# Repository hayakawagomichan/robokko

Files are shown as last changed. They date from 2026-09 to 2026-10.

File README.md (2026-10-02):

# なかよし！ロボっこキット — ATOM S3R

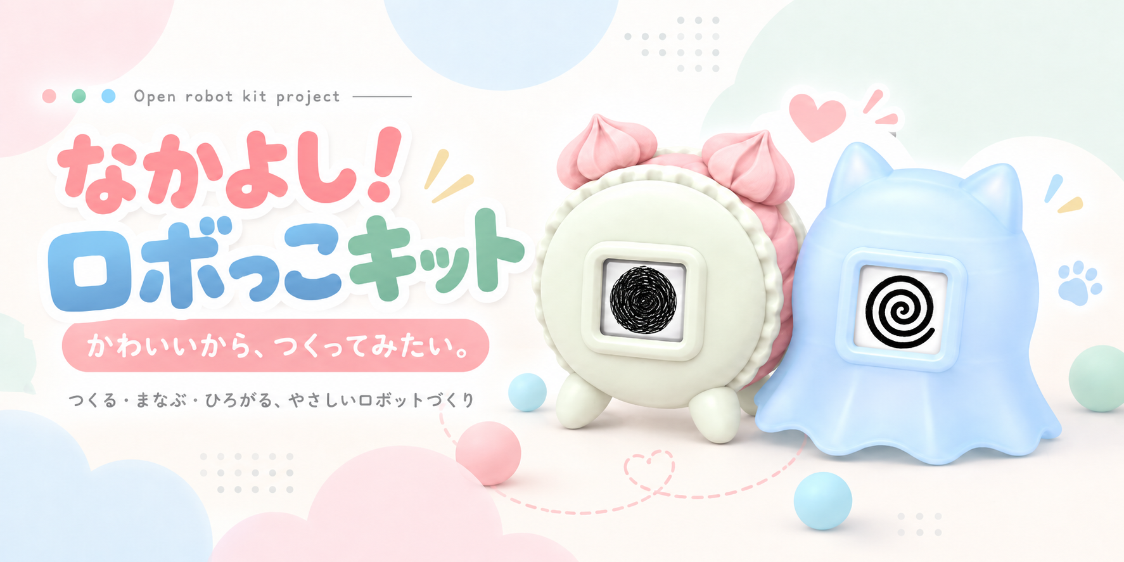
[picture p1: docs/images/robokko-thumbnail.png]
なかよし！ロボっこキット。かわいいから、つくってみたい。


**かわいいから、つくってみたい。気づいたら、ちゃんとロボットをつくってた。**

画面に顔を出して、サーボモーターで動く手のひらサイズのロボットです。
プログラム・作り方・3D印刷データを公開しています。

## 最初にお読みください

- **3Dプリント部品は高温で変形します。** 高温になる場所に置かないでください。
- **ATOMのディスプレイは、強く押し込むと割れることがあります。** 操作は軽く押してください。
- **サーボに負荷がかかるとATOMが再起動することがあります。** 誤った取り付けや、負荷がかかったまま動かし続けるとサーボが壊れる可能性があります。引っかかったら電源を切って確認してください。

**マカロンちゃんはバッテリー必須（組み立て後のUSB給電は非対応）。おばけねこはUSB・対応バッテリーの両方で使えます。**

## 作り方・必要なもの

| 開くページ | 内容 |
| --- | --- |
| [買い物リスト](docs/shopping-list.md) | 電子部品・道具の通販リンクと店舗案内 |
| [3D印刷データ](docs/printing.md) | キャラクター別の部品・個数・Bambu用設定 |
| [写真つき説明書（PDF）](docs/assembly.md) | マカロンちゃん・おばけねこの組み立て |
| 解説動画：[マカロンちゃん](https://youtu.be/42XKh_sF3WY) ／ [おばけねこ](https://youtu.be/PJhalL-63JU) | 組み立ての流れを動画で見る |

## はじめに

以下は **VS Code＋PlatformIO IDE拡張** で、ATOM S3Rにプログラムを書き込む手順です。
用意するものは **PC・ATOM S3R・データ通信できるUSBケーブル**（本体側はType-C）。書き込み済みの方は[配線](#servo-wiring)から進めます。
マカロンも、組み立て前の書き込み・動作確認ではATOM単体をUSBで接続します。

## 1. アプリを準備する（初回だけ）

1. [VS Code](https://code.visualstudio.com/)をインストールします。
2. 左端の「拡張機能」で **PlatformIO IDE** を検索し、提供元がPlatformIOのものをインストールします。
3. 準備が終わるまで待ちます。再起動を求められたらVS Codeを再起動します。

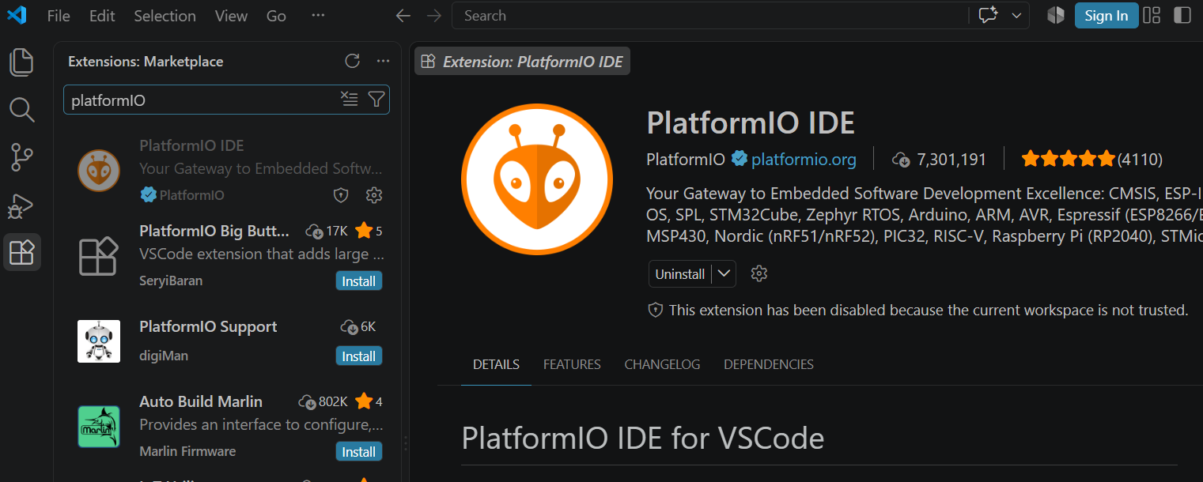
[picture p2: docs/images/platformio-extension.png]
PlatformIO IDE拡張の画面


画像は導入済みの例です。初めて入れるときは「Install」を押します。

## 2. ダウンロードしてフォルダを開く

1. [GitHubのトップ](https://github.com/hayakawagomichan/robokko)で **Code → Download ZIP** を押します。
2. ZIPを展開します。Windowsは右クリック →「すべて展開」、Macはダブルクリック。
3. フォルダを **英数字だけの場所** に置きます。Windowsの例：`C:\robokko`、Macの例：`/Users/hanako/robokko`。途中に日本語があるとビルドに失敗する場合があります。
4. VS Codeで **ファイル → フォルダーを開く** を選び、`platformio.ini` が直接入っているフォルダを開きます。

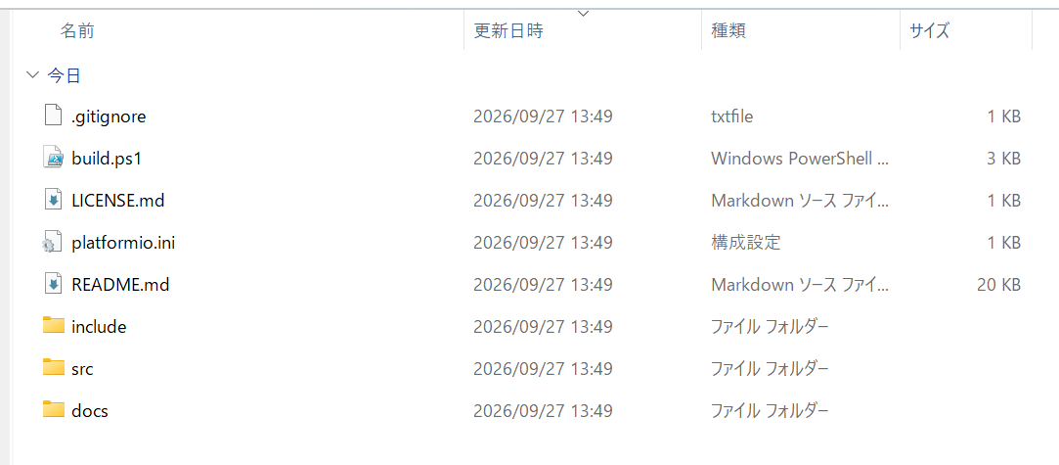
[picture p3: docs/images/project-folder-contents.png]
platformio.iniが入ったフォルダを開きます


`src` はプログラム本体、`include` は顔画像などのデータです。**書き込むだけなら編集不要**です。
フォルダを信頼するか聞かれたら、このGitHubから入手したものと確認して信頼します。初回は道具のダウンロードが終わるまで待ってください。

## 3. 本体をつなぎ、Uploadする

1. **サーボとバッテリーを外し、ATOM S3RだけをUSBでPCにつなぎます。**
2. VS Code左下の **右矢印「→ Upload」** を押します。
3. USBを抜かずに待ち、ターミナルに **SUCCESS** が出たら書き込み完了です。

VS Code左下の右矢印がUploadです。赤枠のボタンを押します。

画像はボタン位置の例です。初回の準備が終わってから押してください。Uploadにはビルドも含まれるので、Buildを別に押す必要はありません。
書き込むと本体の元のプログラムは置き換わります。

## 4. 顔を確認する

USBをつないだまま待つと顔が出ます。本体を横にすると寝顔、縦に戻すと通常の顔になります。
確認できたら **USBを抜いて**、次の配線へ進みます。

## 5. サーボをつなぐ

**配線は電源OFFで行います。** Groveケーブルと4ピン変換コネクタを使い、線の役割を合わせて接続します。

| 役割 | Grove側 | SG90側（今回の実物） |
| --- | --- | --- |
| GND | 黒 | 茶 |
| 5V | 赤 | オレンジ |
| 信号 | 黄・G2 | 黄 |
| 使わない | 白・G1 | 接続しない |

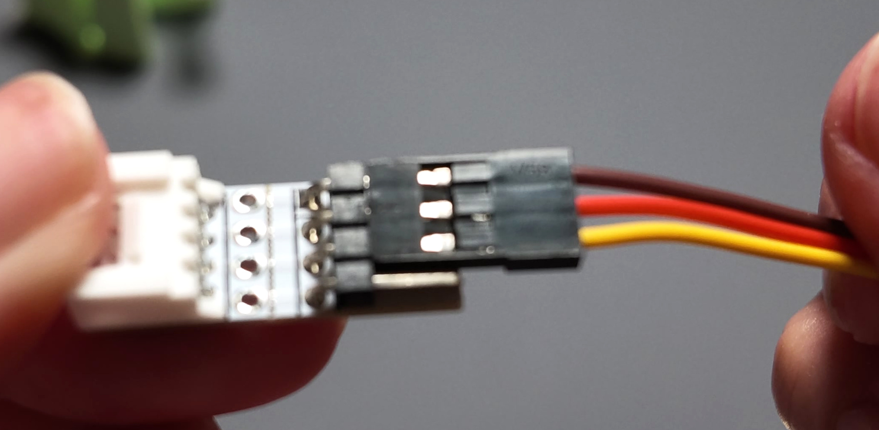
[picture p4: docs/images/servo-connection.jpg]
実物の配線写真


**SG90は製品によって線色が異なります。** 色だけで判断せず、購入品の仕様・端子表示を確認してください。
最初はサーボを機構へ取り付けず、回る部分に物が当たらない状態でUSBをつなぎます。電源を入れるとサーボが動きます。

## 6. 動かしてみる

| 操作 | 動作 |
| --- | --- |
| 画面を1回押す | 往復する／もう1回で元の位置へ戻って止まる |
| 本体を横向きに約2秒保つ | 寝顔になって休止。縦に戻すと往復を再開 |
| 素早く2回押す（ダブルクリック） | **サーボホーンを取り付ける位置へ動き、↑を表示** |
| 本体を軽く振る | 渦巻き顔になる |

ホーンを取り付ける前に、往復を1回押しで止め、**完全に停止してから**ダブルクリックしてください。
[組み立て説明書](docs/assembly.md)へ進みます。次からは電源を入れるだけで遊べます。

## うまくいかないとき

[Uploadボタンがない・書き込めない・サーボが動かない場合はこちら](docs/troubleshooting.md)。

<details>
<summary>プログラムを編集する方へ</summary>

| ファイル | 中身 |
| --- | --- |
| `src/main.cpp` | 顔・ボタン・センサー・サーボの動作 |
| `include/img_*.h` | 顔画像データ |
| `platformio.ini` | ボード設定・使用ライブラリ |
| `build.ps1` | Windows用の書き込み補助 |

PlatformIO espressif32 6.7.0 / Arduino-ESP32 2.0.16。UIFlow2用ではありません。
CLIからの書き込みは `pio run -t upload`。
使用ライブラリ：[M5Unified](https://github.com/m5stack/M5Unified) 0.2.23、[M5GFX](https://github.com/m5stack/M5GFX) 0.2.30、[ESP32Servo](https://github.com/madhephaestus/ESP32Servo) 1.2.1。

</details>

## 利用条件・お問い合わせ

個人利用・非商用ワークショップで利用できます。改造データの再配布は非営利に限り、**Forkまたはクレジット表記＋リンク**で利用できます。元リポジトリへの表示が残るForkでは、追加のクレジット表記は不要です。営利販売は禁止、自分で使う部品の印刷代行はOKです。[利用条件の詳細](LICENSE.md)

**ワークショップ・商用利用の相談 → [なかよしロボティクス](https://nakayoshi.tech)**
不具合の報告 → [GitHub Issues](https://github.com/hayakawagomichan/robokko/issues)

企画・制作：なかよしロボティクス ／ 企画・デザイン：ハヤカワ五味 ／ 設計・3Dデータ：uni

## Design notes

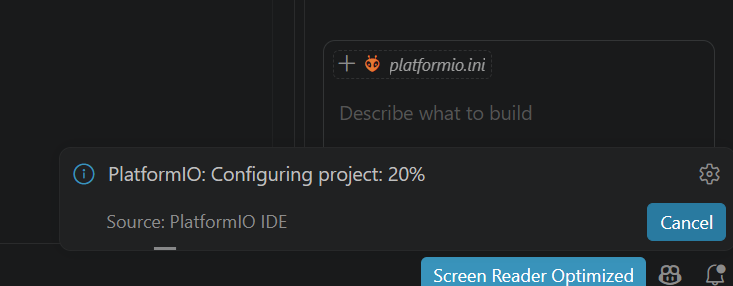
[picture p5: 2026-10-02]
docs/images/platformio-configuring-project.png

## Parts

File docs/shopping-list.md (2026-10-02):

# ロボっこの買い物リスト

[← 書き込み・配線手順](../README.md)

## 1台分の電子部品

価格は2026年9月26日確認・税込・送料別です。現在の価格・在庫は各商品ページをご確認ください。

| 買うもの | 1台に使う数 | 通販の商品リンク・目印 | 購入単位と参考価格 |
| --- | --- | --- | --- |
| 画面付きマイコン本体 | 1台 | スイッチサイエンス：[ATOMS3R（8MB PSRAM搭載）](https://www.switch-science.com/products/9915) / 商品番号 **9915**・型番 **M5STACK-C126** | 1台 **3,531円** |
| サーボモーター | 1個 | 秋月電子通商：[マイクロサーボ9g SG90](https://akizukidenshi.com/catalog/g/g108761/) / 販売コード **108761** | 1個 **650円** |
| 本体と変換コネクタをつなぐケーブル | 1本 | スイッチサイエンス：[M5Stack用GROVE互換ケーブル 10 cm](https://www.switch-science.com/products/5213) / 商品番号 **5213**・型番 **M5STACK-A034**（旧表記：M5STACK-CABLE-10） | **5本セット**で **528円** |
| サーボをつなぐ変換コネクタ | 1個 | スイッチサイエンス：[GROVE用4ピン変換コネクタ](https://www.switch-science.com/products/7093) / 商品番号 **7093**・型番 **M5STACK-A099** | **10個セット**で **847円** |
| PCと本体をつなぐUSBケーブル | 1本 | 手持ちの**データ通信対応**ケーブルでOK。PCにUSB-A端子がある場合の購入例：秋月電子通商 [USB2.0 Type-A ⇔ Type-C 1.5 m](https://akizukidenshi.com/catalog/g/g113563/) / 販売コード **113563** | 購入例は1本 **130円** |

- 本体は**画面付きATOM S3R（C126）**、サーボは通常のSG90を選びます。Liteや360°連続回転サーボは対象外です。
- USBケーブルは**データ通信対応**で、PC側の端子に合うものを選んでください。
- SG90は製品によって線色が異なります。[配線表](../README.md#servo-wiring)と購入品の仕様を照合してください。

## 費用の目安

本体・サーボ・Groveケーブル・変換コネクタを販売単位で購入すると **5,556円＋送料**。USBケーブルも上の例で買うと **5,686円＋送料**です。
セットを分けた場合、1台に使う基本の電子部品は約4,371円分。**マカロンには下記バッテリー代も必須**です。3D印刷・道具の代金は別です。

## バッテリー（マカロンは必須／おばけねこは任意）

**マカロンちゃんはバッテリー必須です。組み立て後のUSB給電には対応していません。**
マカロンちゃんと、コードレスで使うおばけねこには、[ATOMIC バッテリーベース](https://www.switch-science.com/products/10375)を1個用意します。
型番 **M5STACK-A151／200 mAh**。1個 **1,232円**（2026年10月2日確認・税込・送料別）。

- 使うとき：スイッチ **ON**。
- 充電するとき：スイッチ **OFF**でATOMにUSBを接続。青LEDが充電中、緑LEDが完了です。
- 着脱するとき：USBを抜き、スイッチをOFFにします。

出力上限は5 V・300 mA。使い方は[メーカー説明](https://docs.m5stack.com/en/atom/Atomic_Battery_Base)へ。
バッテリーを使わないおばけねこには、[バッテリーなし用スペーサー](printing.md#common)が1個必要です。マカロンにはスペーサーを使いません。

## 組み立てに使うもの

| 用意するもの | 購入・入手先 |
| --- | --- |
| 外装・機構の部品 | [3D印刷データ・必要個数](printing.md) |
| 精密プラスドライバー | サーボ付属のねじに合うもの |
| 接着剤 | 瞬間接着剤、または[ボンド ウルトラ多用途SU](https://www.amazon.co.jp/dp/B0CJWWBTYD)など |

接着は[説明書](assembly.md)の位置に行い、動く部分には付けないでください。乾燥時間は接着剤の説明に従います。

## 店頭で買うなら（東京・秋葉原）

| 店 | 買うもの | 所在地・営業時間 |
| --- | --- | --- |
| [千石電商 秋葉原本店](https://www.sengoku.co.jp/shop_01.html) | [ATOM S3R](https://www.sengoku.co.jp/mod/sgk_cart/detail.php?code=EEHD-6J74)・接続部品 | 外神田1-8-6 丸和ビル／11:00〜19:00 |
| [秋月電子通商 秋葉原店](https://akizukidenshi.com/catalog/pages/akiba.aspx) | SG90・USBケーブル | 外神田1-8-3 野水ビル／11:00〜18:00 |

店舗情報は2026年9月26日確認。休業日・店頭在庫は各店の公式案内をご確認ください。

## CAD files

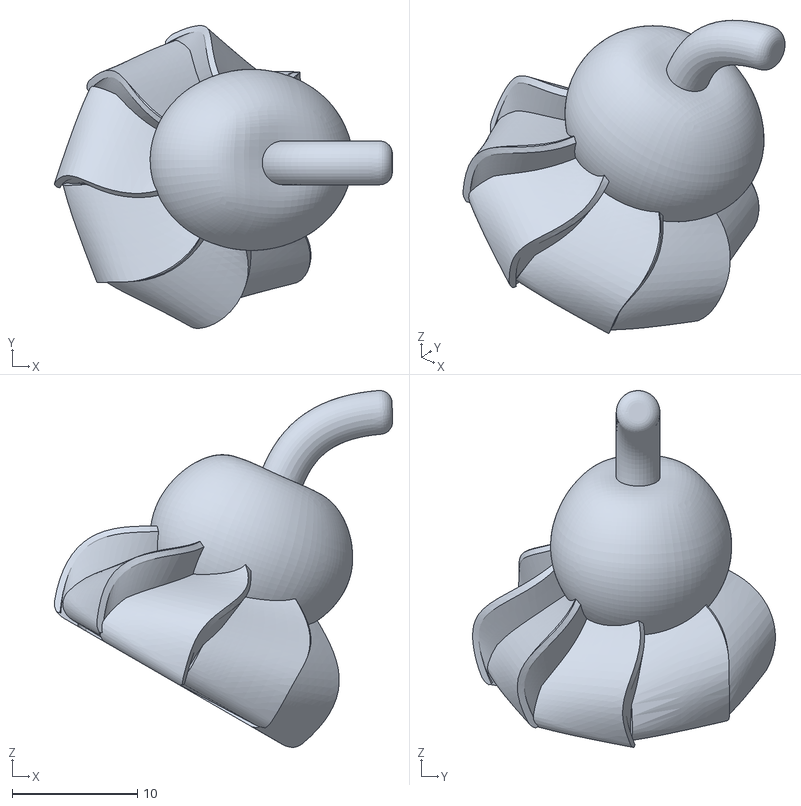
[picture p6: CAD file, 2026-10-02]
models/別仕様_要確認/マカロン/さくらんぼホイップ.stl
27.0 x 24.2 x 28.5

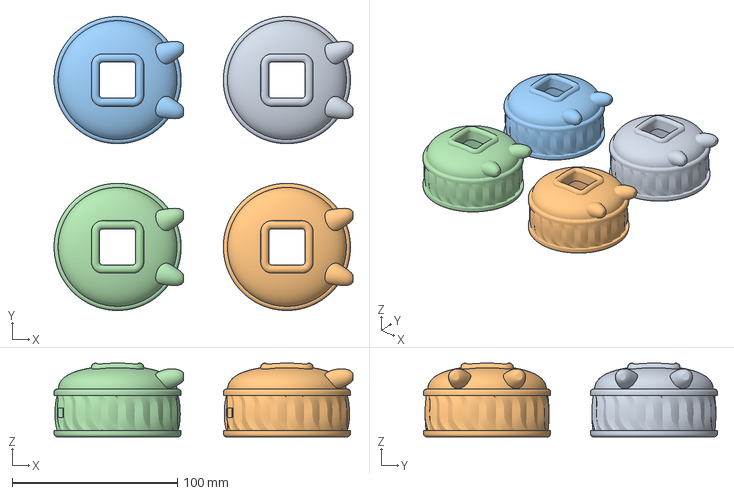
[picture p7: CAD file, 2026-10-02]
models/印刷設定_BambuP2S専用/マカロン_本体_4台分.3mf
181.0 x 178.0 x 44.7 mm
マカロン前クリアランス0.3.stl x 4

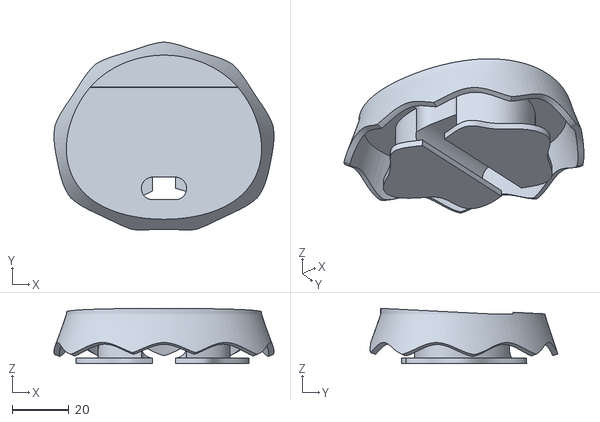
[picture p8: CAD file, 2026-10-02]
models/印刷部品/おばけねこ/足.stl
77.8 x 66.4 x 19.5

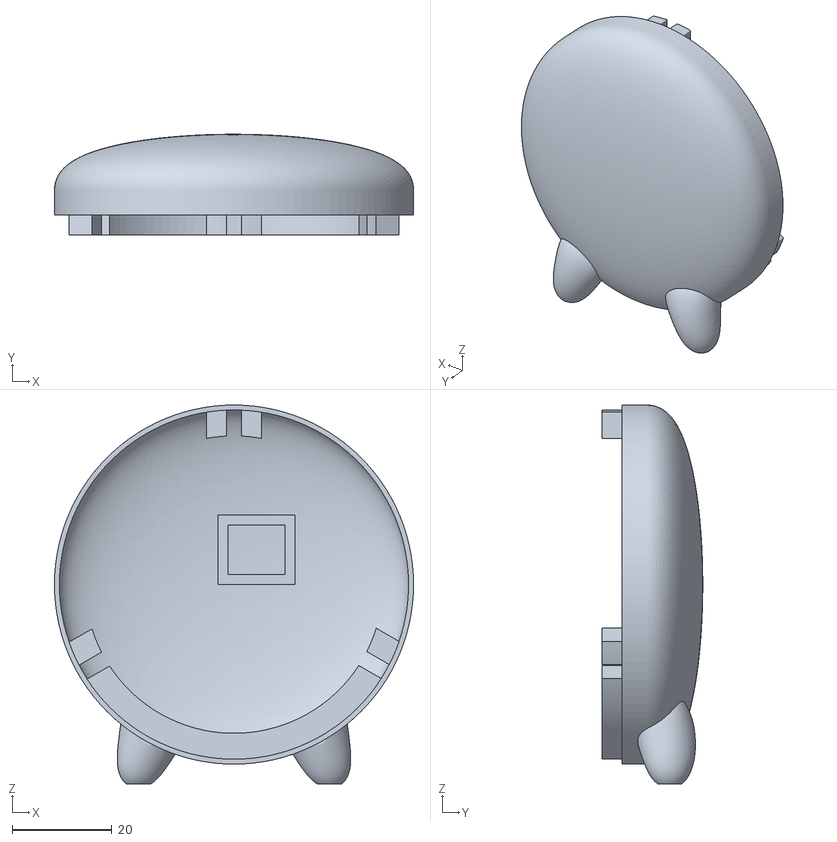
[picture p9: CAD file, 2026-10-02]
models/印刷部品/マカロン/ふた.stl
72.0 x 20.2 x 76.0

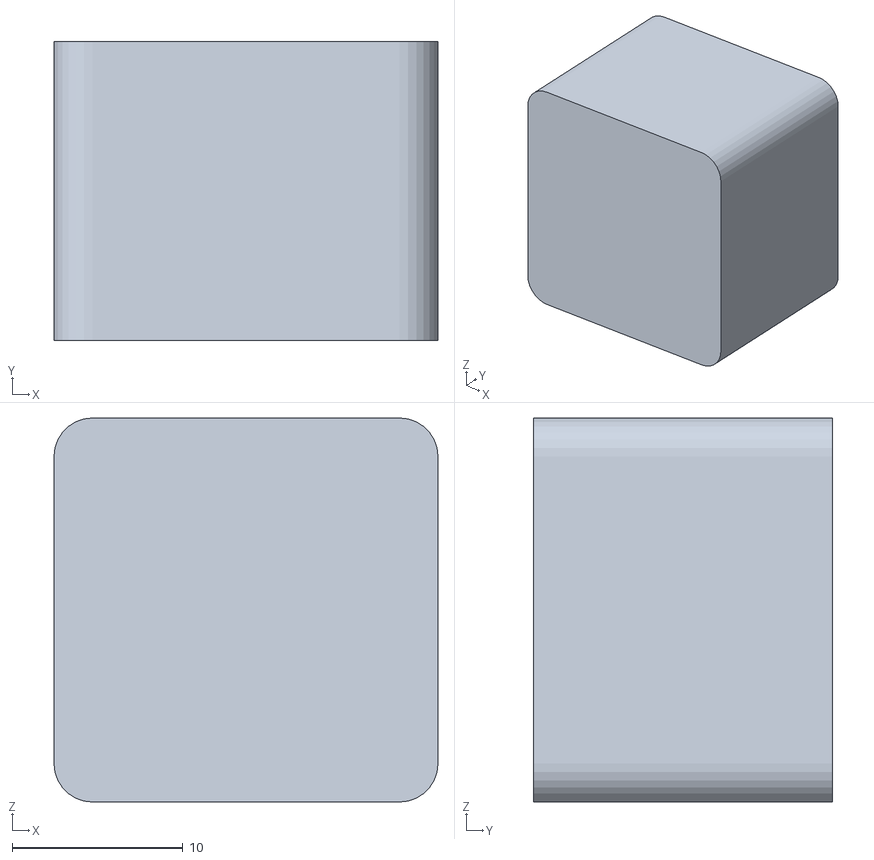
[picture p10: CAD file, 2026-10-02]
models/印刷部品/共通/バッテリーなし用スペーサー.stl
22.5 x 17.5 x 22.5

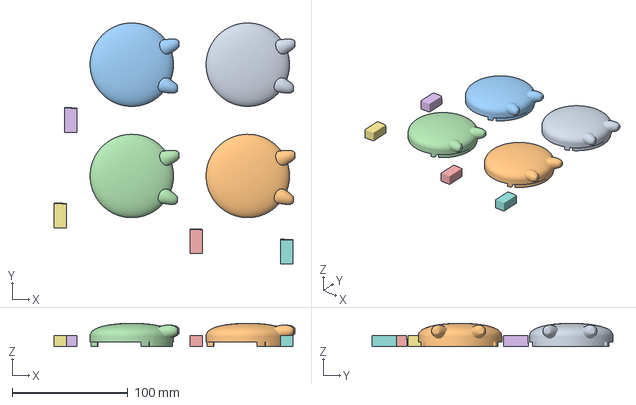
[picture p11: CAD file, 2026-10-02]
models/印刷設定_BambuP2S専用/マカロン_ふたとつっかえ棒_4台分.3mf
207.9 x 208.0 x 20.2 mm
マカロン後ろ穴なし.stl x 4
バッテリーアリつっかえ棒.stl x 4

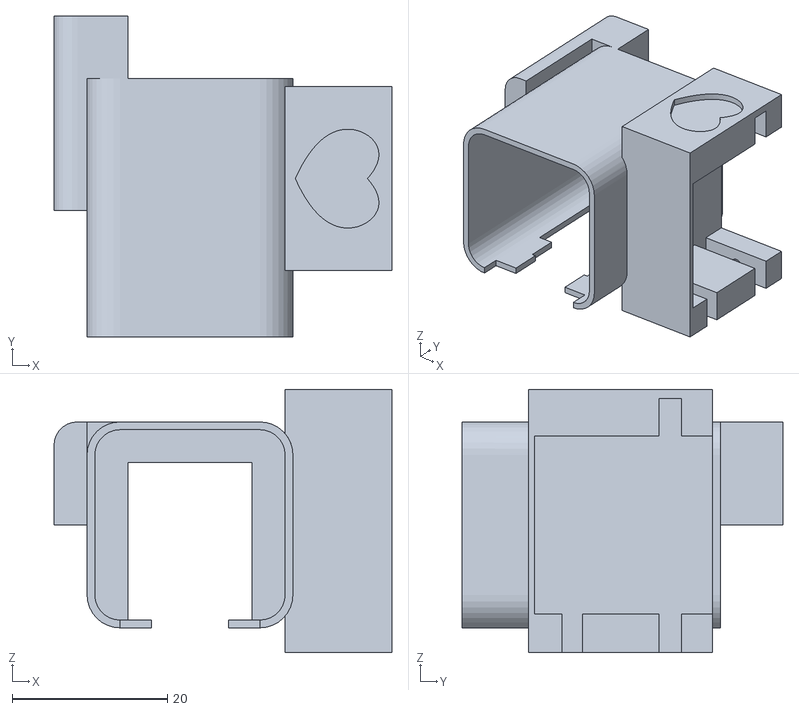
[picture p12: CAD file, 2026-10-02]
models/印刷部品/おばけねこ/ソケット.stl
43.5 x 41.2 x 33.9

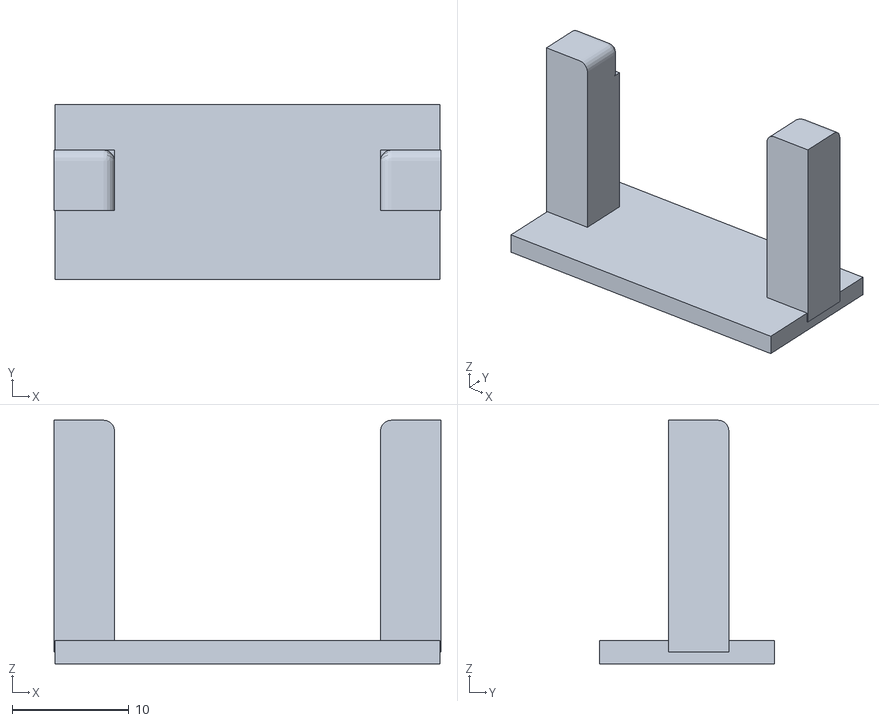
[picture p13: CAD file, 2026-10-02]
models/印刷部品/マカロン/軸.stl
33.2 x 15.0 x 20.9

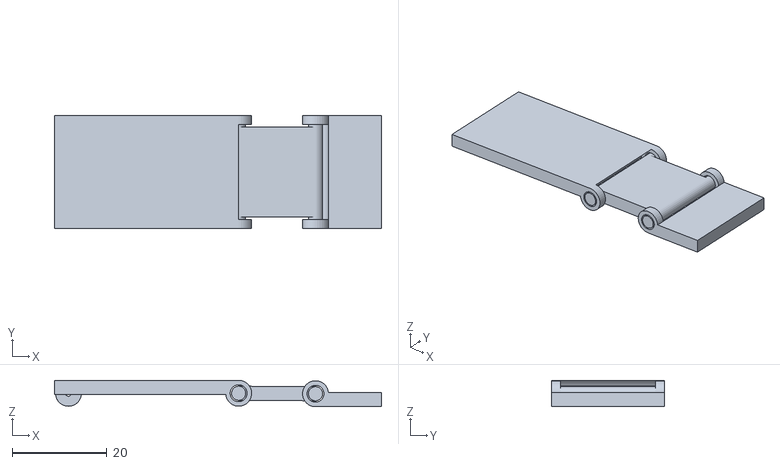
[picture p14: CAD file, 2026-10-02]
models/印刷部品/共通/ヒンジ.stl
69.2 x 24.0 x 5.60

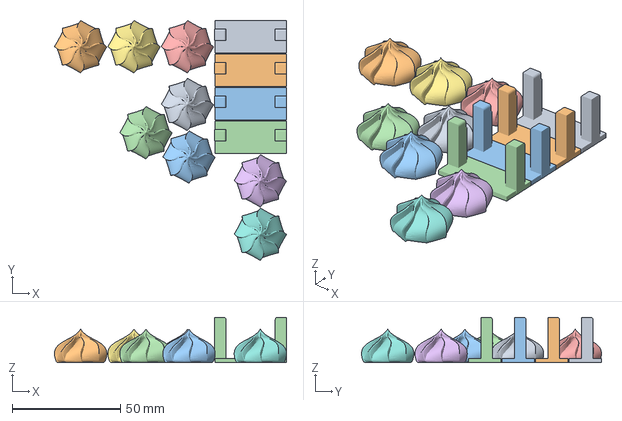
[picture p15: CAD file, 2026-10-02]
models/印刷設定_BambuP2S専用/マカロン_ホイップと軸_4台分.3mf
107.2 x 110.8 x 20.9 mm
マカロン耳軸.stl x 4
マカロンホイップ (1).stl x 8

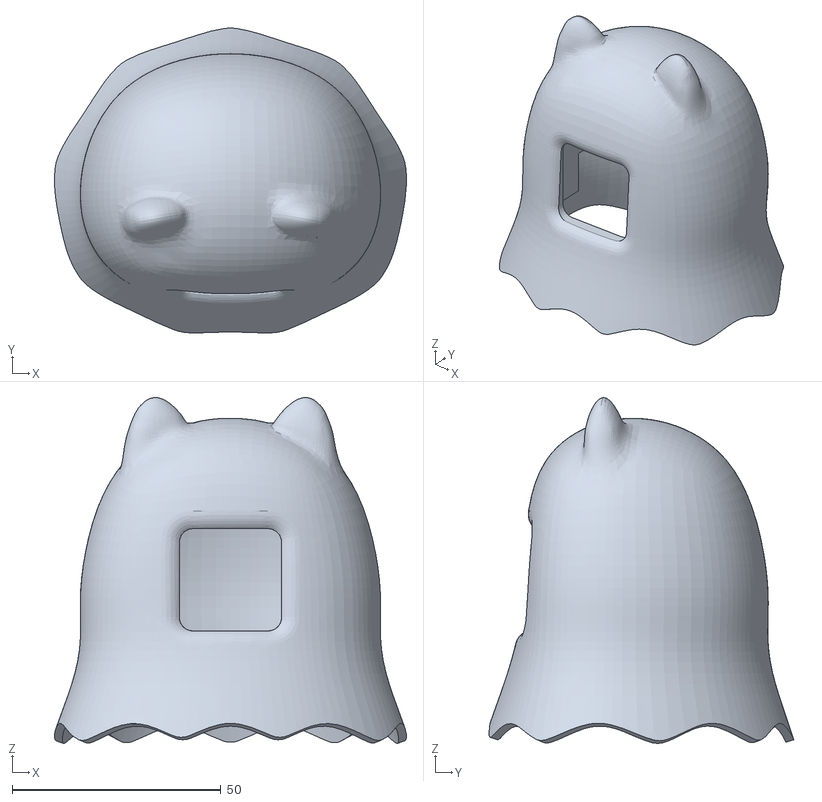
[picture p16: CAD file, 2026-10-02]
models/印刷部品/おばけねこ/本体.stl
84.3 x 73.0 x 82.8

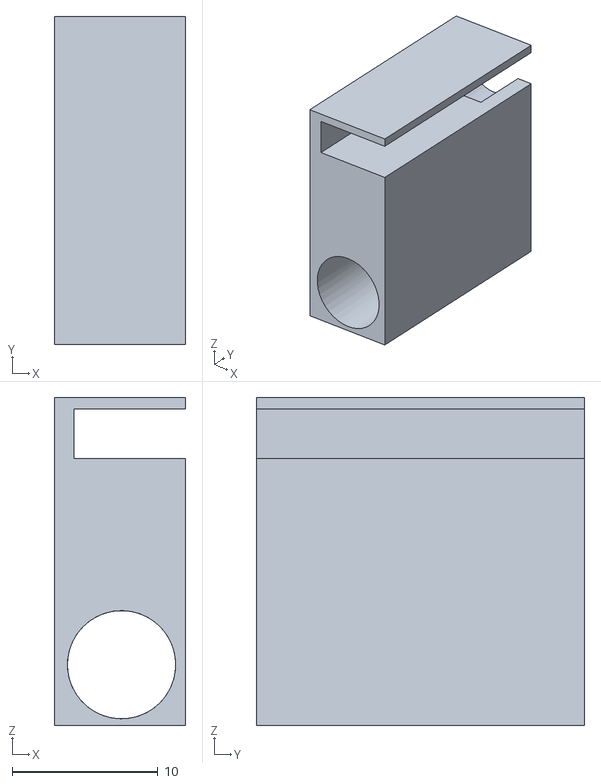
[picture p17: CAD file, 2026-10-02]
models/印刷部品/共通/組み立て用の台.stl
9.00 x 22.5 x 22.5

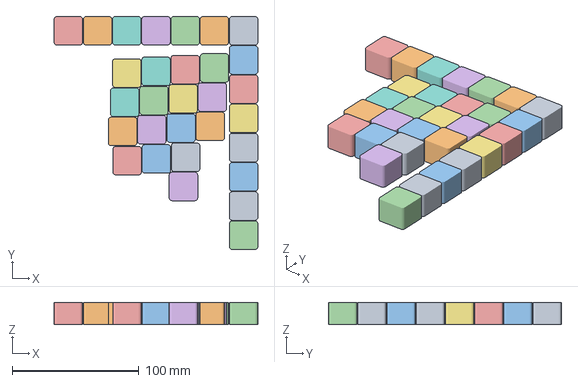
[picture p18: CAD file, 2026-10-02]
models/印刷設定_BambuP2S専用/バッテリーなし用スペーサー_30個.3mf
160.5 x 183.5 x 17.5 mm
バッテリー替わり２.stl x 30

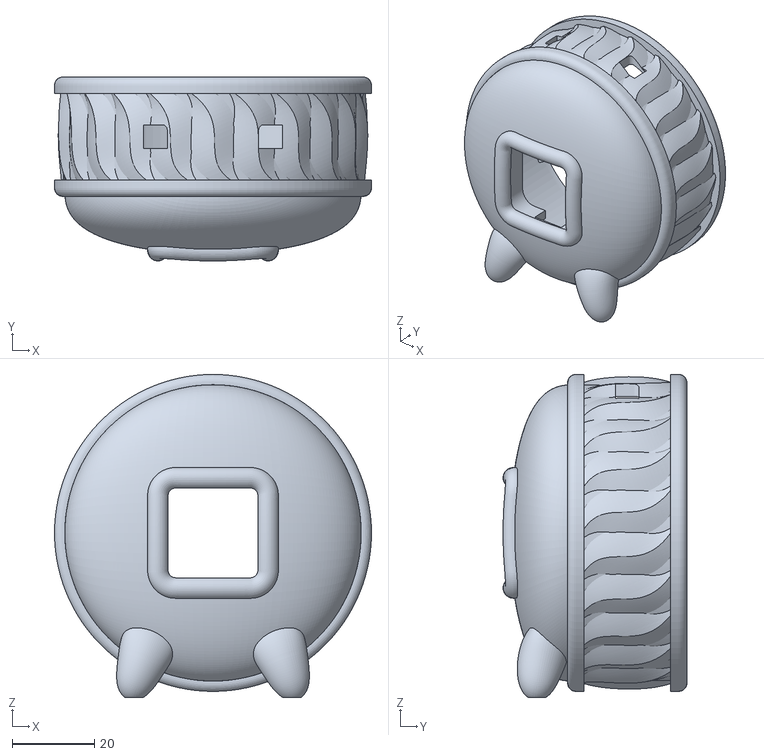
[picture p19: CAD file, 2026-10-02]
models/印刷部品/マカロン/本体.stl
77.0 x 44.7 x 78.5

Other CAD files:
models/参考のみ_スライス済み/ヒンジと組み立て用の台_P2S_0.4mmノズル.gcode.3mf
models/印刷部品/マカロン/ソケット.stl
models/印刷部品/マカロン/つっかえ棒.stl
models/印刷部品/マカロン/ホイップ.stl

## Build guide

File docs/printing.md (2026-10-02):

# 3Dプリントで部品を作る

**3Dプリントした部品は、高温で変形します。**

作りたいキャラクターの部品と[共通部品](#common)を印刷してください。電子部品は[買い物リスト](shopping-list.md)、組み立ては[説明書](assembly.md)へ。

## ダウンロード

下のリンクで個別に保存できます。一式なら[トップページ](../README.md)の **Code → Download ZIP** でダウンロードし、解凍後の `models` フォルダを開きます。

| 形式 | 使い方 |
| --- | --- |
| **STL** | 部品の形。自分のプリンター用のスライサーで印刷設定を作ります。 |
| **3MF** | 形・配置・印刷条件。収録データはP2S用です。Bambu Studioで**プロジェクトとして**開きます。 |
| **gcode.3mf** | P2S用の計算済み印刷命令。編集用の形状は入っていません。 |

## マカロンちゃん：1台分

**バッテリー専用・USB給電非対応です。** 下の部品に加え、[共通部品](#common)のヒンジと台、[対応バッテリー](shopping-list.md#battery)が必要です。スペーサーは使いません。

| 部品名 | 個数 | STL |
| --- | ---: | --- |
| 本体 | 1 | [本体.stl](../models/印刷部品/マカロン/本体.stl?raw=true) |
| ふた | 1 | [ふた.stl](../models/印刷部品/マカロン/ふた.stl?raw=true) |
| ホイップ | **2** | [ホイップ.stl](../models/印刷部品/マカロン/ホイップ.stl?raw=true) |
| 軸 | **1** | [軸.stl](../models/印刷部品/マカロン/軸.stl?raw=true) |
| つっかえ棒 | 1 | [つっかえ棒.stl](../models/印刷部品/マカロン/つっかえ棒.stl?raw=true) |
| ソケット | 1 | [ソケット.stl](../models/印刷部品/マカロン/ソケット.stl?raw=true) |

軸は、2本の突起がつながった1つの部品です。

## おばけねこ：1台分

**USB給電／バッテリーを選べます。** 下の部品に加え、[共通部品](#common)も用意してください。

| 部品名 | 個数 | STL |
| --- | ---: | --- |
| 本体 | 1 | [本体.stl](../models/印刷部品/おばけねこ/本体.stl?raw=true) |
| 足 | 1 | [足.stl](../models/印刷部品/おばけねこ/足.stl?raw=true) |
| ソケット | 1 | [ソケット.stl](../models/印刷部品/おばけねこ/ソケット.stl?raw=true) |

ソケットはキャラクター専用です。マカロン用と取り違えないでください。

## 共通部品

| 部品名 | 1台分の個数 | STL |
| --- | --- | --- |
| ヒンジ | 1組 | [ヒンジ.stl](../models/印刷部品/共通/ヒンジ.stl?raw=true) |
| 組み立て用の台 | 1（繰り返し使用可） | [組み立て用の台.stl](../models/印刷部品/共通/組み立て用の台.stl?raw=true) |
| バッテリーなし用スペーサー | マカロン：0／おばけねこ：USB給電なら1、バッテリー使用なら0 | [バッテリーなし用スペーサー.stl](../models/印刷部品/共通/バッテリーなし用スペーサー.stl?raw=true) |

台はねじ留め用の道具です。組み立て後に取り外します。

## 印刷のポイント

- **mm・倍率100%**で読み込みます。
- **ヒンジは、なるべく細いノズルで細かく印刷**してください。
- 印刷方向・積層・サポートは、下の3MFを参考に、自分の機種と材料に合わせて設定します。
- 印刷後はサポートを除去します。マカロンの軸穴も確認してください。

### Bambu Lab P2S用：設定付き3MF

4ファイルとも **P2S・0.4 mmノズル・積層0.24 mm・PLA** の設定です。必要な個数に減らして使えます。STLと重複して印刷する必要はありません。

| 3MF | 収録内容 |
| --- | --- |
| [マカロン：本体・4台分](../models/印刷設定_BambuP2S専用/マカロン_本体_4台分.3mf?raw=true) | 本体4個 |
| [マカロン：ふたとつっかえ棒・4台分](../models/印刷設定_BambuP2S専用/マカロン_ふたとつっかえ棒_4台分.3mf?raw=true) | ふた4個＋つっかえ棒4個 |
| [マカロン：ホイップと軸・4台分](../models/印刷設定_BambuP2S専用/マカロン_ホイップと軸_4台分.3mf?raw=true) | ホイップ8個＋軸4個 |
| [バッテリーなし用スペーサー・30個](../models/印刷設定_BambuP2S専用/バッテリーなし用スペーサー_30個.3mf?raw=true) | スペーサー30個 |

おばけねこの外装・ソケット、マカロンのソケットはSTLのみです。

### ヒンジと台：印刷例（スライス済み）

[ヒンジと組み立て用の台.gcode.3mf](../models/参考のみ_スライス済み/ヒンジと組み立て用の台_P2S_0.4mmノズル.gcode.3mf?raw=true)

収録条件は **P2S・0.4 mmノズル・積層0.16 mm**。より細いノズルなどに変更するときは、上のヒンジ・台のSTLからスライスし直してください。
**他機種・異なるノズル構成に、この印刷命令をそのまま送らないでください。**

## 別仕様

[さくらんぼホイップ.stl](../models/別仕様_要確認/マカロン/さくらんぼホイップ.stl?raw=true)：組み立て方は説明書に未掲載。通常版は上の「ホイップ」2個を使います。

---

次は[組み立て説明書](assembly.md)へ。利用条件は[LICENSE.md](../LICENSE.md)をご覧ください。

設計・3Dデータ作成：uni／企画・制作：なかよしロボティクス

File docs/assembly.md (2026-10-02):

# ロボっこの組み立て説明書

## 最初にお読みください

- 3Dプリント部品は**高温で変形**します。
- ATOMの画面は**強く押し込むと割れることがあります**。軽く押してください。
- サーボへの負荷でATOMが再起動することがあります。**誤った取り付けや負荷をかけたままの運転は故障の原因**になるため、引っかかったら電源を切ってください。

**マカロンちゃんはバッテリー必須（組み立て後のUSB給電は非対応）。おばけねこはUSB・対応バッテリーの両方で使えます。**

| キャラクター | カラーPDF | YouTube |
| --- | --- | --- |
| マカロンちゃん | [説明書](manuals/macaron-a4-color.pdf) | [組み立て動画](https://youtu.be/42XKh_sF3WY) |
| おばけねこ | [説明書](manuals/obakeneko-a4-color.pdf) | [組み立て動画](https://youtu.be/PJhalL-63JU) |

PDFは **A4・両面・長辺とじ・実際のサイズ（100%）** で印刷します。

## 準備

[部品・道具](shopping-list.md) ／ [3D印刷データ](printing.md) ／ [プログラムの書き込み](../README.md#はじめに)

配線・電池の着脱・接着は**電源OFF**で行います。USBを抜き、バッテリーのスイッチもOFFにしてください。

## 手順3：ホーンを付けたあと、もう一度確認

1. 往復していたら画面を1回押し、完全に止まるまで待ちます。
2. **ダブルクリックでホーンを取り付ける位置に合わせます。** ↑が出て動きが止まったら、ホーンを真上に向けて取り付けます。電源ONのままでも取り付けられます。
3. **もう一度ダブルクリックし、止まったときにホーンが真上か確認**します。ずれていたら付け直して再確認します。
4. 向きが合ったら電源を切り、ヒンジをソケットに固定します（接着推奨）。

マカロンのつっかえ棒は**ふたの内側**へ接着。おばけねこは足をかぶせ、ひっくり返して完成です。

ワークショップ・商用利用の相談：[なかよしロボティクス](https://nakayoshi.tech)

企画・制作：なかよしロボティクス ／ 企画・デザイン：ハヤカワ五味 ／ 設計・3Dデータ：uni

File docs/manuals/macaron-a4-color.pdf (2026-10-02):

なかよし！ロボっこキット

# マカロンちゃんの作り方

おもて：部品と書き込み ／ うら：写真で見る組み立て

はじめに

・3Dプリント部品は高温で変形します。
・ATOMの画面は強く押し込むと割れます。
・サーボに負荷がかかるとATOMが再起動することがあります。取り付けを間違えたり、 負荷をかけたまま動かし続けたりするとサーボが壊れることがあります。

## 1 部品を確認する

外装
本体・ふた、ホイップ、軸、つっかえ棒

しくみ
ソケット、ヒンジ、組み立て用の台

動かす部品
SG90サーボ、最小のホーンとねじ

つなぐ部品
Groveケーブル、4ピン変換アダプタ

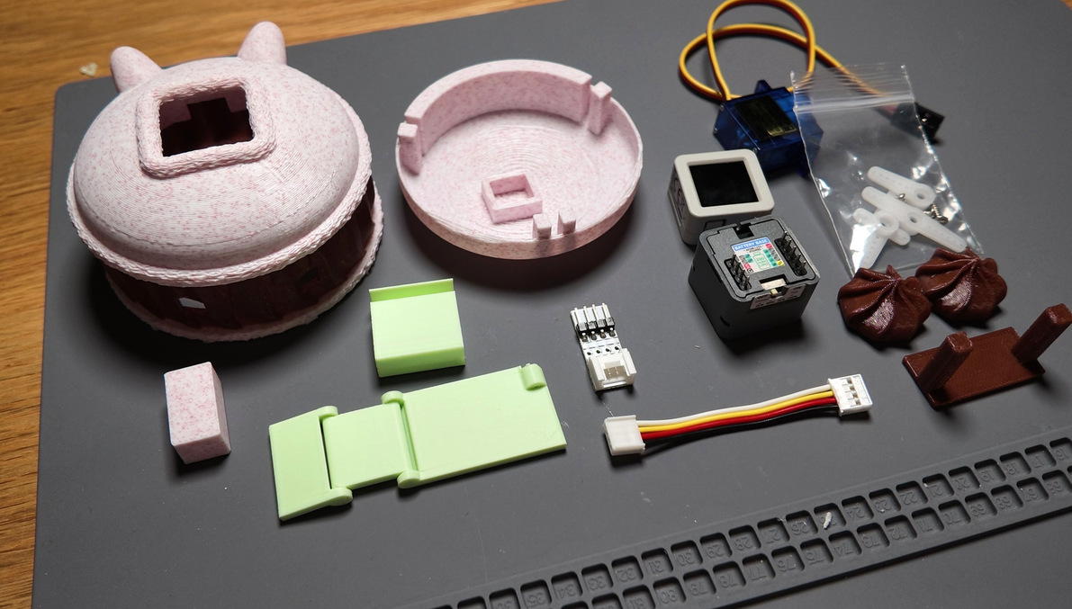
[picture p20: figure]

写真には別売のATOM S3R・バッテリーも含みます。

## 2 別途用意するもの

ATOM S3R（画面つき）／PC・ネット／データ通信対応USBケーブル（本体側Type-C）／ねじに合う精密プラスドライバー／瞬間接着剤 または ボンドウルトラ多用途SU

マカロンはバッテリー必須。ATOMIC Battery Base / M5STACK-A151（200mAh）。 完成後のUSB給電は非対応。スペーサーは使いません。USBは下の書き込み時のみ使います。

## 3 ATOM S3Rに書き込む

書き込み済みの方は、裏面へ。

A アプリを入れる
VS Codeを入れ、左の「拡張機能」から「PlatformIO IDE」をインストールします。

B プログラムをダウンロード
下のGitHubで「Code」→「Download ZIP」を選び、ZIPを展開。Windowsでは C:\robokko など、途中も英数字だけの場所に置きます。

C フォルダを開く
VS Codeの「ファイル」→「フォルダーを開く」で、platformio.ini が入ったフォルダを選び、初回の準備が終わるまで待ちます。

D USBでつないでUpload
ATOM S3RだけをPCへ接続。画面下の「→ Upload」を押し、USBを抜かずに待ちます。SUCCESS が出て顔が表示されたら完了です。

Uploadでビルドも自動実行されます。

### 詳しい書き込み・買い物リスト・困ったときは

https://github.com/hayakawagomichan/robokko

充電専用のUSBケーブルでは書き込めません。

改訂：2026-10-02
なかよしロボティクス ｜ 企画・デザイン ハヤカワ五味 ／ 設計・3Dデータ uni | 1/2

なかよし！ロボっこキット

# マカロンちゃんの作り方

うら：配線・接着は電源OFF。ホーンは③の手順で。
電源OFF＝バッテリーをOFF。

## 1 ヒンジを組み立てる

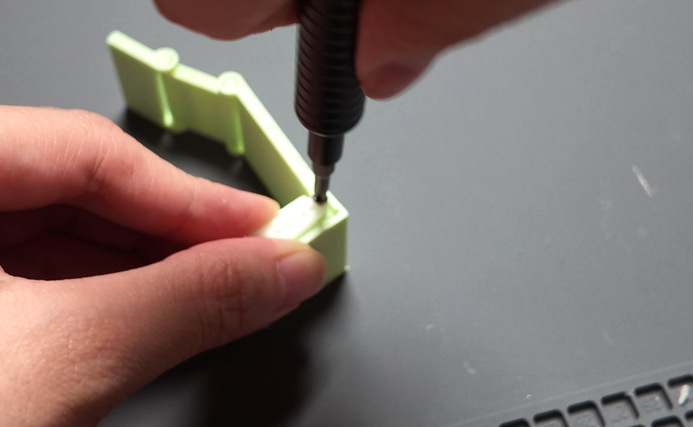
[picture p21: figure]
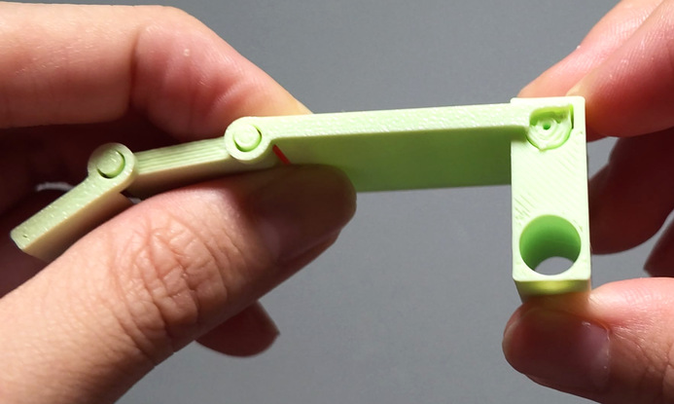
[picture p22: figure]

向きを合わせる | 台で支えて、ねじ留め

ヒンジを組み立て用の台にはめ、穴に最小のホーンを入れます。 上から押さえ、最小のねじで留めます。締めすぎず、指で軽く 押すと動く程度に。最後に台を外します。

## 2 サーボとケーブルをつなぐ

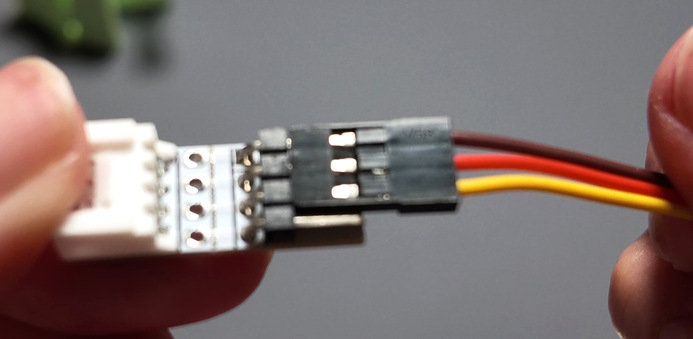
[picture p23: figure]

サーボ側の接続例（共通）

サーボ → Grove
茶 → 黒：GND
オレンジ → 赤：5V
黄 → 黄：G2（信号）
白はつなぎません。

アダプタを使い、電源と信号の位置を合わせて接続します。線 色は今回のキットで確認したものです。色だけでなく端子の表 示も確認しましょう。

## 3 角度を合わせて取り付ける

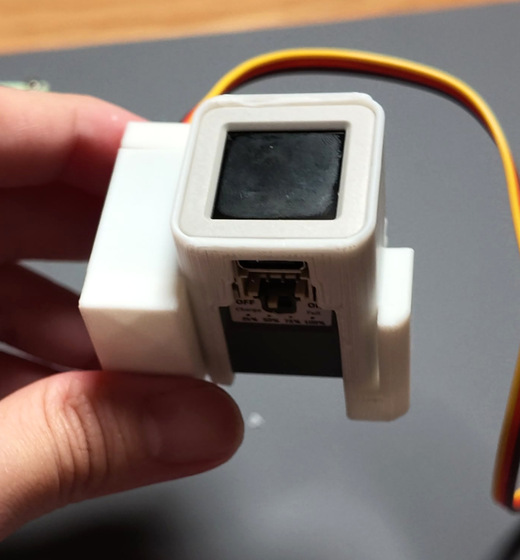
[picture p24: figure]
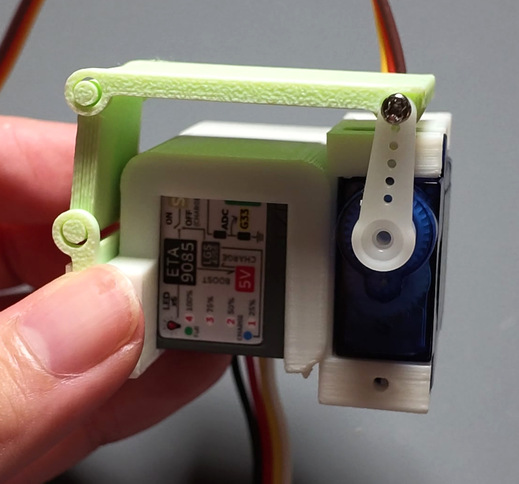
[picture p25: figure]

本体とサーボを収める | 白いホーンが真上 | 向きの確認後に固定

写真は配置・向き・固定位置の参考です。
中央は共通機構の例。確認は右の順番で。

バッテリーをOFFにしてATOMに取り付け、サーボ・ Grove端子とソケットへ。
A 電源を入れる。往復中なら画面を1回押し、完
全に止まるまで待つ。
B 画面を素早く2回押すと、ホーンの取り付け位
置に移動し「↑」が出る。止まったらホーンを真
上に付ける（電源ONのままでOK）。
C もう一度2回押し、停止後に真上か確認。ずれ
ていたら付け直して再確認。
D 電源を切り、ヒンジをソケットに固定（接着推
奨）。

## 4 ホイップを付ける

軸を通す | ホイップを接着

軸穴の造形サポートを取り除き、足を上に
して軸を通します。軸を押さえてホイップ
を接着。動く部分に接着剤が入らないよう
にし、十分乾かします。

## 5 中身を収める

コードを隙間へ収める

ソケットを外装に入れます。コードは下を
通して隙間へ。動く部分に引っかからず、
ふたで挟まない位置へ収めます。

## 6 ふたを閉める

ふたの内側に接着 | 完成！

つっかえ棒をふたの内側に接着します。乾
いたらコードを挟まないようにふたを閉め
ます。電源を入れ、画面を1回押すと往復
運動、もう1回で停止。

接着剤は商品の説明に従い、十分に乾かします。動きが引っかかるときは電源を切って確認してください。
改訂：2026-10-02
なかよしロボティクス ｜ 企画・デザイン ハヤカワ五味 ／ 設計・3Dデータ uni | 2/2

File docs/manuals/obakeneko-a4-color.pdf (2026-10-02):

なかよし！ロボっこキット

# おばけねこの作り方

おもて：部品と書き込み ／ うら：写真で見る組み立て

はじめに

・3Dプリント部品は高温で変形します。
・ATOMの画面は強く押し込むと割れます。
・サーボに負荷がかかるとATOMが再起動することがあります。取り付けを間違えたり、 負荷をかけたまま動かし続けたりするとサーボが壊れることがあります。

### 1 部品を確認する

外装
本体・足

しくみ
ソケット、ヒンジ、組み立て用の台

動かす部品
SG90サーボ、最小のホーンとねじ

つなぐ部品
Groveケーブル、4ピン変換アダプタ

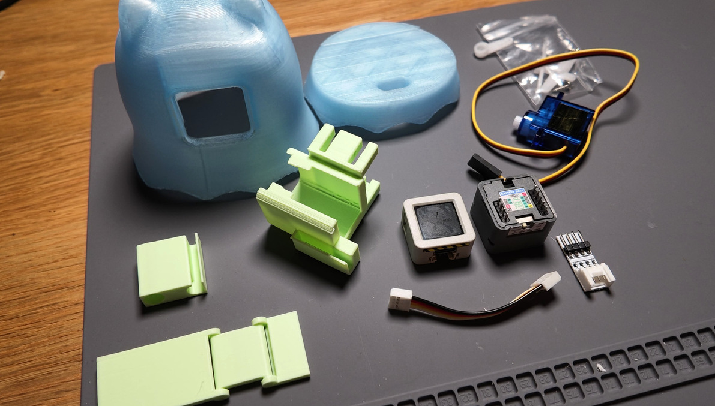
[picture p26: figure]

写真には別売のATOM S3R・バッテリーも含みます。

### 2 別途用意するもの

ATOM S3R（画面つき）／PC・ネット／データ通信対応USBケーブル（本体側Type-C）／ねじに合う精密プラスドライバー／瞬間接着剤 または ボンドウルトラ多用途SU

バッテリー（任意）：ATOMIC Battery Base / M5STACK-A151（200mAh）。
使わない場合は専用スペーサーを使い、USBから給電します。

### 3 ATOM S3Rに書き込む

書き込み済みの方は、裏面へ。

A アプリを入れる
VS Codeを入れ、左の「拡張機能」から「PlatformIO IDE」をインストールします。

B プログラムをダウンロード
下のGitHubで「Code」→「Download ZIP」を選び、ZIPを展開。Windowsでは C:\robokko など、途中も英数字だけの場所に置きます。

C フォルダを開く
VS Codeの「ファイル」→「フォルダーを開く」で、platformio.ini が入ったフォルダを選び、初回の準備が終わるまで待ちます。

D USBでつないでUpload
ATOM S3RだけをPCへ接続。画面下の「→ Upload」を押し、USBを抜かずに待ちます。SUCCESS が出て顔が表示されたら完了です。

Uploadでビルドも自動実行されます。

詳しい書き込み・買い物リスト・困ったときは

https://github.com/hayakawagomichan/robokko

充電専用のUSBケーブルでは書き込めません。

改訂：2026-10-02
なかよしロボティクス ｜ 企画・デザイン ハヤカワ五味 ／ 設計・3Dデータ uni | 1/2

なかよし！ロボっこキット

# おばけねこの作り方

うら：配線・接着は電源OFF。ホーンは③の手順で。
電源OFF＝USBを抜く／バッテリーをOFF。

### 1 ヒンジを組み立てる

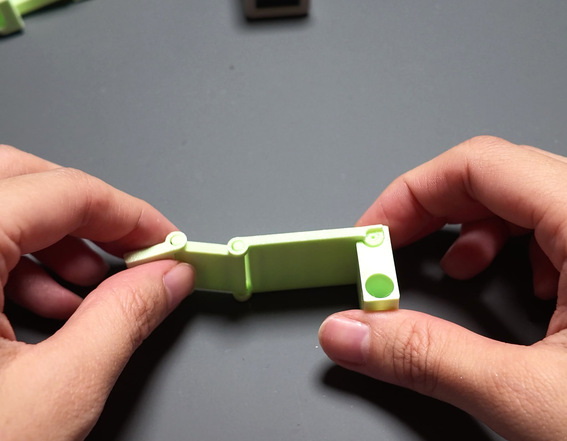
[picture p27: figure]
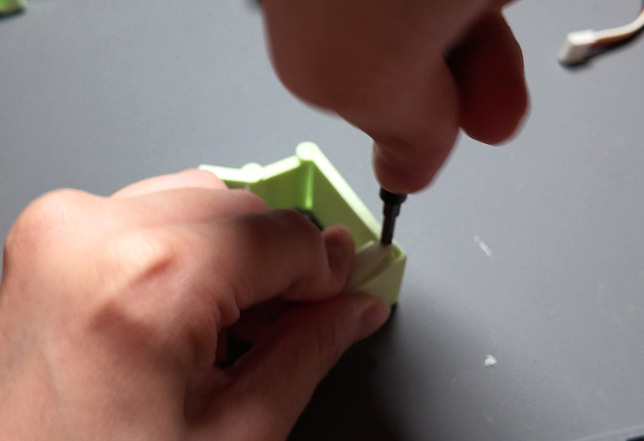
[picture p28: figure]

向きを合わせる | 台で支えて、ねじ留め

ヒンジを組み立て用の台にはめ、穴に最小のホーンを入れます。 上から押さえ、最小のねじで留めます。締めすぎず、指で軽く 押すと動く程度に。最後に台を外します。

### 2 サーボとケーブルをつなぐ


サーボ側の接続例（共通）

サーボ → Grove
茶 → 黒：GND
オレンジ → 赤：5V
黄 → 黄：G2（信号）
白はつなぎません。

アダプタを使い、電源と信号の位置を合わせて接続します。線 色は今回のキットで確認したものです。色だけでなく端子の表 示も確認しましょう。

### 3 角度を合わせて取り付ける

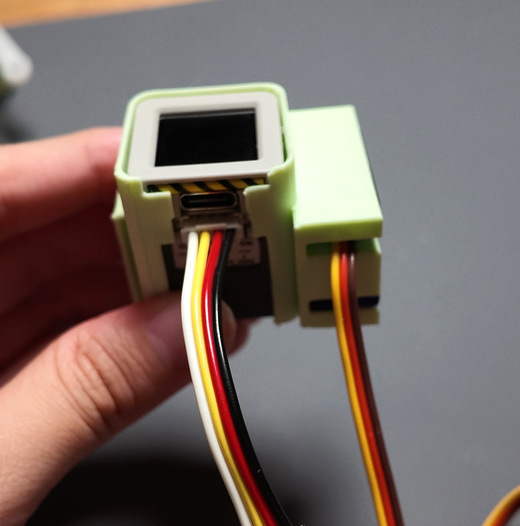
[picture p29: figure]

本体とサーボを収める | 白いホーンが真上 | 向きの確認後に固定

写真は配置・向き・固定位置の参考です。
中央は共通機構の例。確認は右の順番で。

サーボ・ATOM・Grove端子をソケットへ。
A 電源を入れる。往復中なら画面を1回押し、完
全に止まるまで待つ。
B 画面を素早く2回押すと、ホーンの取り付け位
置に移動し「↑」が出る。止まったらホーンを真
上に付ける（電源ONのままでOK）。
C もう一度2回押し、停止後に真上か確認。ずれ
ていたら付け直して再確認。
D 電源を切り、ヒンジをソケットに固定（接着推
奨）。

### 4 中身とコードを収める

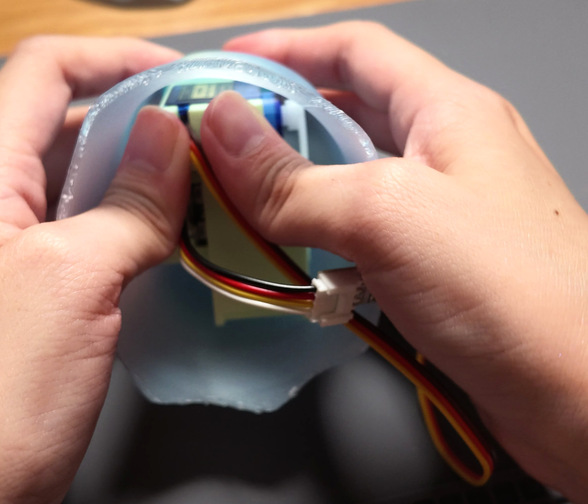
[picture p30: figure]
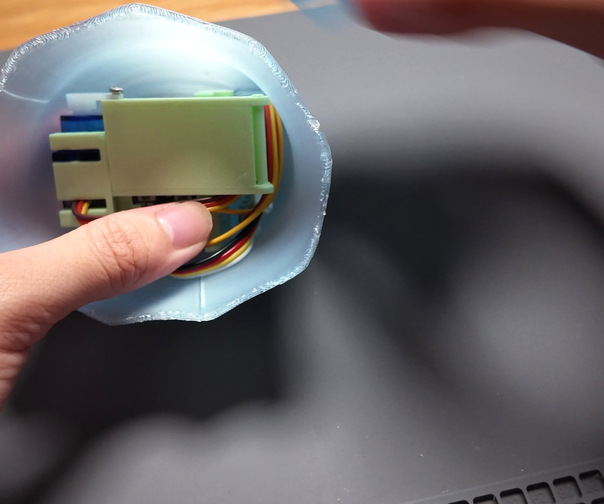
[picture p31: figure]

ソケットを外装へ | コードを隙間へ

ソケットを外装に入れ、画面の位置を合わせます。コードは動 く部分に引っかからないよう、隙間に収めます。

### 5 足をかぶせ、ひっくり返す

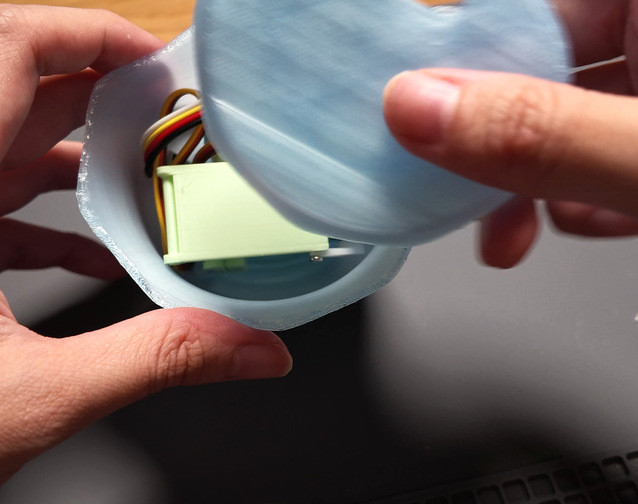
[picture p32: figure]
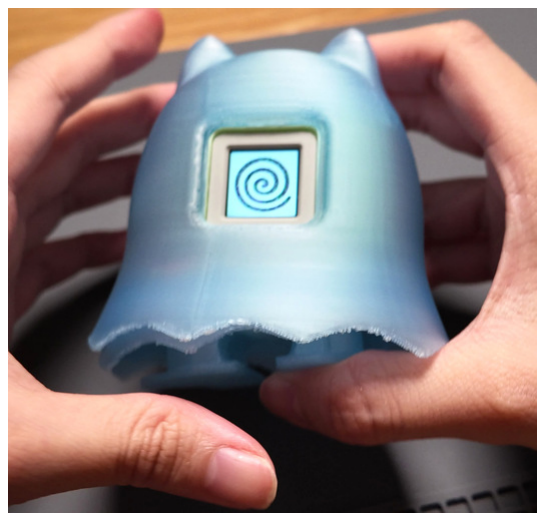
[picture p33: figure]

コードを挟まずに足をかぶせる ひっくり返したら完成！

コードを挟まないよう足をかぶせ、全体をひっくり返します。 電源を入れ、画面を1回押すと往復運動、もう1回で停止します。

接着剤は商品の説明に従い、十分に乾かします。動きが引っかかるときは電源を切って確認してください。
改訂：2026-10-02
なかよしロボティクス ｜ 企画・デザイン ハヤカワ五味 ／ 設計・3Dデータ uni | 2/2

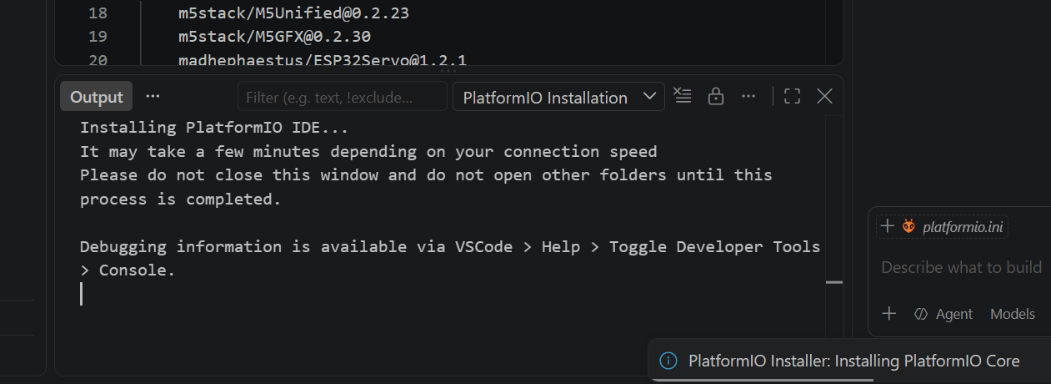
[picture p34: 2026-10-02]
docs/images/platformio-first-install.png

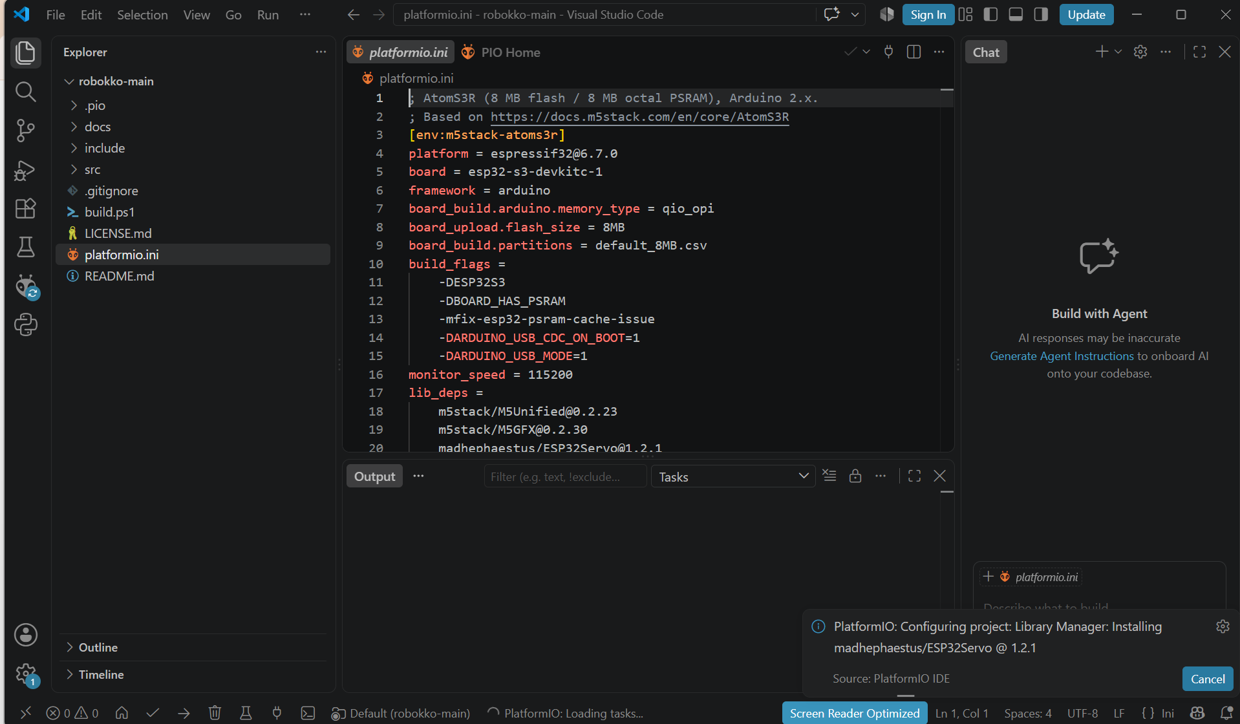
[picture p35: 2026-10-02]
docs/images/platformio-library-install.png

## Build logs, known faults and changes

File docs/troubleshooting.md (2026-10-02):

# 書き込みで困ったとき

[← 書き込み手順](../README.md#はじめに)

## Uploadボタンが見つからない

左側のPlatformIOアイコン → **PROJECT TASKS → m5stack-atoms3r → General → Upload** を選びます。
項目が出ない場合は、拡張機能の準備が終わったか、`platformio.ini` が入ったフォルダを開いているかを確認してください。

## 顔やサーボが動かない

| 症状 | 確認すること |
| --- | --- |
| 画面が消えた | USBの接続。バッテリー使用時はスイッチと充電残量 |
| SUCCESSなのに顔が出ない | USBを抜き差しする。画面付きATOM S3Rか確認 |
| 顔は出るがサーボが動かない | 電源を切り、[GND・5V・G2の配線](../README.md#servo-wiring)を確認 |
| 引っかかる・うなる・再起動する | すぐ電源を切り、取り付け・配線・機構の引っかかりを確認 |

### ビルド用ファイルが見つからないとき

`bootloader_qio_80m.elf` や `freertos/FreeRTOS.h` が見つからず、エラーの場所が `.platformio/packages/framework-arduinoespressif32/` の中を指している場合は、PCに入ったビルド用パッケージが欠けている可能性があります。
これはGitHubから受け取るロボっこのファイルとは別に、PlatformIOが準備するものです。

まず、[フォルダの置き場所](../README.md#download)の英数字の場所を使っていることと、初回のダウンロードが終わったことを確認します。それでも同じ場合は、次の方法で該当パッケージを入れ直せます。**正常にビルドできる方は実行不要です。**

1. 実行中のBuild・Uploadを止め、インターネットにつなぎます。
2. VS Codeのコマンドパレット（Windowsは `Ctrl + Shift + P`、Macは `⌘ + Shift + P`）で **`PlatformIO: Open PlatformIO Core CLI`** を選びます。
3. 開いたターミナルで、次の1行を実行します。このプロジェクトが使用しているバージョンのビルド用パッケージを再インストールします。同じパッケージを使う他のPlatformIOプロジェクトにも共通の環境です。

```sh
pio pkg install --global --tool "platformio/framework-arduinoespressif32@3.20016.0" --force
```

4. 再インストールが完了したら「✓ Build」で確認し、成功してから「→ Upload」を押します。

解決しない場合は、エラーの全文を[Issues](https://github.com/hayakawagomichan/robokko/issues)へお寄せください。ユーザー名などの個人情報は伏せて構いません。
[PlatformIO公式：パッケージの再インストール](https://docs.platformio.org/en/stable/core/userguide/pkg/cmd_install.html)

### 書き込み先が見つからないとき

`Please specify` と `upload_port` を含むエラーや、その次の `For some development platforms it can be a USB flash drive` という表示は、書き込み先を自動検出できなかったときに出ます。ATOM S3RでUSBメモリーを用意するという意味ではありません。

1. ATOM S3Rを**データ通信対応のUSBケーブルでPCへ**つなぎます。画面がついていても、充電専用ケーブルでは書き込めません。
2. いったん抜き差しし、可能ならPCの別のUSB端子や、通信できることがわかっているケーブルを試します。
3. 下の方法で本体を**書き込みモード**にして、もう一度Uploadを押します。
4. Windowsの「デバイス マネージャー」→「ポート（COMとLPT）」で本体のCOM番号が表示されるのに失敗する場合は、下の「COM番号」の手順で接続先を指定します。番号が出ない場合は、ケーブルとUSB接続を確認してください。

先にBuildを実行しても、接続先が見つからない状態ではUploadは成功しません。エラーを相談するときは、末尾の `FAILED` だけでなく、**少し上の `Error:` から始まる行**も見せてください。
[PlatformIO公式：接続先の自動検出とupload_port](https://docs.platformio.org/en/latest/projectconf/sections/env/options/upload/upload_port.html)

### 書き込みモードにする方法

本体の **リセットボタン** を約2秒長押しし、内部の緑LEDが点灯したら離します。
画面部分の操作ボタンとは別のボタンです。その後、もう一度 **Upload** を押してください。
[M5Stack公式の説明と写真](https://docs.m5stack.com/en/core/AtomS3R)

<details>
<summary>接続先の「COM番号」を指定したいとき（Windows）</summary>

1. Windowsのスタートボタンを右クリックして「デバイス マネージャー」を開きます。
2. 「ポート（COMとLPT）」を開き、ATOM S3Rをつないだときに増える項目の番号を確認します。例：`COM4`。
3. 自動検出でうまくいかない場合は、`platformio.ini` の末尾に `upload_port = COM4` を追加して保存し、Uploadします。番号は自分のPCで確認したものに置き換えてください。

書き込みモードにしたり、USBの接続先を変えたりすると番号が変わる場合があります。
別のPCへ渡すときは、追加した `upload_port` の行を削除して自動検出に戻してください。

</details>

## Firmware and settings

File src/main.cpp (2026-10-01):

// M5Stack AtomS3R - servo sweep toggled by the front button (BtnA)
//
// Wiring: connect the servo to the Grove (Port.A) connector.
//   Grove black (GND) -> servo GND (brown on the tested kit)
//   Grove red (5V)    -> servo power (orange on the tested kit)
//   Grove yellow (G2) -> servo signal (yellow on the tested kit)
// Servo wire colors vary by product; confirm the actual pin functions.
// If your servo cable uses the other signal wire, change SERVO_PIN to 1 (G1).
//
// Display:
//   - SWEEP OFF             -> default face
//   - SWEEP ON               -> random idle animation (see ANIM_PATTERNS below)
//   - Landscape held 2 sec   -> return to rest and pause an active sweep
//   - Shake                  -> guruguru face briefly

#include <M5Unified.h>
#include <ESP32Servo.h>
#include <math.h>
#include "img_default.h"
#include "img_left.h"
#include "img_right.h"
#include "img_sleep.h"
#include "img_guruguru.h"

static const int SERVO_PIN = 2;      // Grove G2
static const int SWEEP_MIN_ANGLE = 20;
static const int SWEEP_MAX_ANGLE = 65;
static const int SWEEP_STEP_DEG = 2; // degrees moved per update
static const unsigned long SWEEP_INTERVAL_MS = 25;
static const int REST_ANGLE = SWEEP_MAX_ANGLE; // position when OFF

static const float ORIENTATION_MARGIN_G = 0.15f;  // hysteresis between portrait/landscape
static const unsigned long LANDSCAPE_SLEEP_HOLD_MS = 2000; // landscape must hold this long (while sweeping) to pause+sleep
static const float SHAKE_THRESHOLD_G = 1.4f;      // deviation from 1g that counts as a shake
static const unsigned long SHAKE_DISPLAY_MS = 800;

static const unsigned long ARROW_DISPLAY_MS = 800;
static const int DOUBLE_CLICK_ANGLE = 20;         // every double-click commands this same position

// Idle animation shown while sweeping, picked randomly (weighted) each time a pattern finishes.
struct AnimStep {
    const uint16_t *image;
    unsigned long durationMs;
};

static const AnimStep ANIM_PATTERN_DEFAULT[] = { { img_default, 2000 } };
static const AnimStep ANIM_PATTERN_LOOK_AROUND[] = { { img_right, 1000 }, { img_default, 1000 }, { img_left, 1000 } };
static const AnimStep ANIM_PATTERN_BLINK[] = { { img_sleep, 500 } };

static const AnimStep *ANIM_PATTERNS[] = { ANIM_PATTERN_DEFAULT, ANIM_PATTERN_LOOK_AROUND, ANIM_PATTERN_BLINK };
static const int ANIM_PATTERN_LENGTHS[] = { 1, 3, 1 };
static const int ANIM_PATTERN_WEIGHTS[] = { 70, 10, 20 }; // must sum to 100
static const int ANIM_PATTERN_COUNT = 3;

Servo servo;
bool sweeping = false;
int angle = REST_ANGLE;
int direction = -1; // first move away from REST_ANGLE (which sits at the max end)
unsigned long lastStepMs = 0;

bool isLandscape = false;
bool prevIsLandscape = false;
unsigned long landscapeStartMs = 0;
bool sweepPaused = false;
bool returningToRest = false; // easing angle back to REST_ANGLE instead of snapping
unsigned long lastShakeMs = 0;
unsigned long lastDoubleClickMs = 0;
bool shakeActive = false;
bool arrowActive = false;

static const uint16_t *IMAGE_ARROW = reinterpret_cast<const uint16_t *>(1); // sentinel: procedurally drawn, not pushImage'd
const uint16_t *currentImage = nullptr;

int animPatternIndex = -1; // -1 = needs to pick a fresh pattern
int animStepIndex = 0;
unsigned long animStepStartMs = 0;

int pickAnimPattern() {
    int r = random(100); // 0..99
    int acc = 0;
    for (int i = 0; i < ANIM_PATTERN_COUNT; i++) {
        acc += ANIM_PATTERN_WEIGHTS[i];
        if (r < acc) return i;
    }
    return ANIM_PATTERN_COUNT - 1;
}

const uint16_t *getIdleAnimationImage() {
    unsigned long now = millis();
    if (animPatternIndex < 0 ||
        now - animStepStartMs >= ANIM_PATTERNS[animPatternIndex][animStepIndex].durationMs) {
        if (animPatternIndex < 0) {
            animPatternIndex = pickAnimPattern();
            animStepIndex = 0;
        } else {
            animStepIndex++;
            if (animStepIndex >= ANIM_PATTERN_LENGTHS[animPatternIndex]) {
                animPatternIndex = pickAnimPattern();
                animStepIndex = 0;
            }
        }
        animStepStartMs = now;
    }
    return ANIM_PATTERNS[animPatternIndex][animStepIndex].image;
}

void drawArrowUp() {
    M5.Display.fillScreen(TFT_BLACK);
    M5.Display.fillTriangle(64, 20, 30, 68, 98, 68, TFT_WHITE);
    M5.Display.fillRect(50, 68, 28, 40, TFT_WHITE);
}

void showImage(const uint16_t *img) {
    if (img == currentImage) return;
    if (img == IMAGE_ARROW) {
        drawArrowUp();
    } else {
        M5.Display.pushImage(0, 0, 128, 128, img);
    }
    currentImage = img;
}

void setup() {
    auto cfg = M5.config();
    M5.begin(cfg);
    randomSeed(esp_random());

    servo.setPeriodHertz(50);
    servo.attach(SERVO_PIN, 500, 2400);
    servo.write(angle);

    showImage(img_default);
}

void loop() {
    M5.update();

    if (M5.BtnA.wasSingleClicked()) {
        sweeping = !sweeping;
        if (sweeping) {
            returningToRest = false; // resume actively right away
            sweepPaused = false;
            animPatternIndex = -1; // start fresh
        } else {
            returningToRest = true; // ease down to REST_ANGLE instead of snapping
        }
    }
    if (M5.BtnA.wasDoubleClicked()) {
        lastDoubleClickMs = millis();
        arrowActive = true;
        // Keep the next sweep/return step relative to the last commanded position.
        angle = DOUBLE_CLICK_ANGLE;
        direction = (angle == REST_ANGLE) ? -1 : 1;
        lastStepMs = lastDoubleClickMs;
        servo.write(angle);
    }

    M5.Imu.update();
    auto imu = M5.Imu.getImuData();
    float ax = imu.accel.x;
    float ay = imu.accel.y;
    float az = imu.accel.z;

    if (fabsf(ax) > fabsf(ay) + ORIENTATION_MARGIN_G) {
        isLandscape = true;
    } else if (fabsf(ay) > fabsf(ax) + ORIENTATION_MARGIN_G) {
        isLandscape = false;
    }

    if (isLandscape && !prevIsLandscape) {
        landscapeStartMs = millis();
    }
    if (!isLandscape && sweepPaused) {
        sweepPaused = false; // wake up as soon as it's back to portrait
        returningToRest = false; // resume actively right away
    }
    prevIsLandscape = isLandscape;

    if (sweeping && !sweepPaused && isLandscape && (millis() - landscapeStartMs >= LANDSCAPE_SLEEP_HOLD_MS)) {
        sweepPaused = true;
        returningToRest = true; // ease down to REST_ANGLE before holding still
    }

    float magnitude = sqrtf(ax * ax + ay * ay + az * az);
    if (fabsf(magnitude - 1.0f) > SHAKE_THRESHOLD_G) {
        lastShakeMs = millis();
        shakeActive = true;
    }
    if (shakeActive && millis() - lastShakeMs >= SHAKE_DISPLAY_MS) {
        shakeActive = false;
    }
    if (arrowActive && millis() - lastDoubleClickMs >= ARROW_DISPLAY_MS) {
        arrowActive = false;
    }

    if (arrowActive) {
        showImage(IMAGE_ARROW);
    } else if (shakeActive) {
        showImage(img_guruguru);
    } else if (sweeping) {
        showImage(sweepPaused ? img_sleep : getIdleAnimationImage());
    } else {
        // not sweeping: screen just tracks orientation directly, no hold delay
        showImage(isLandscape ? img_sleep : img_default);
    }

    if (returningToRest) {
        unsigned long now = millis();
        if (now - lastStepMs >= SWEEP_INTERVAL_MS) {
            lastStepMs = now;
            if (angle > REST_ANGLE) {
                angle = max(REST_ANGLE, angle - SWEEP_STEP_DEG);
            } else if (angle < REST_ANGLE) {
                angle = min(REST_ANGLE, angle + SWEEP_STEP_DEG);
            }
            servo.write(angle);
            if (angle == REST_ANGLE) {
                returningToRest = false;
                direction = -1; // first move away from REST_ANGLE (which sits at the max end)
            }
        }
    } else if (sweeping && !sweepPaused) {
        unsigned long now = millis();
        if (now - lastStepMs >= SWEEP_INTERVAL_MS) {
            lastStepMs = now;
            angle += direction * SWEEP_STEP_DEG;
            if (angle >= SWEEP_MAX_ANGLE) {
                angle = SWEEP_MAX_ANGLE;
                direction = -1;
            } else if (angle <= SWEEP_MIN_ANGLE) {
                angle = SWEEP_MIN_ANGLE;
                direction = 1;
            }
            servo.write(angle);
        }
    }
}

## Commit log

2026-09-26 Publish ATOM S3R face display and servo firmware
2026-09-26 Update README.md
    初心者向けに読みやすい内容にするため(Codex用に)改善点を洗い出しました。
2026-09-26 docs: explain optional battery power for portable use
2026-09-27 docs: explain upload port detection errors and USB cable checks
2026-10-01 fix: use the same servo angle on every double-click
    [main.cpp]
2026-10-01 docs: add photo assembly guides for Macaron and Obakeneko
2026-10-01 docs: preserve printable PDF files as binary
2026-10-02 docs: publish print models and complete beginner assembly guidance
    [さくらんぼホイップ.stl, つっかえ棒.stl, ふた.stl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]
2026-10-02 docs: add assembly video links
2026-10-02 docs: simplify guides and clarify macaron battery requirements
2026-10-02 docs: link revised macaron assembly video
